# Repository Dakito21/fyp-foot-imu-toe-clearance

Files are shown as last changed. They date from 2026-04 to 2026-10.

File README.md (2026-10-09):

# Foot-Mounted IMU Estimation of Minimum Toe Clearance

Final Year Project, Robotics and Mechatronic Engineering, Monash University (2026).
Supervisor: Dr Alpha Agape Gopalai.

Minimum toe clearance (MTC) is the smallest gap between the toe and the ground during the swing phase of walking, and is closely linked to trip and fall risk. It is normally measured with optical motion capture (MoCap), which only works in a lab. This project estimates MTC from a single foot-mounted IMU instead. It also includes a low-cost wearable IMU (BMI160 + Seeed XIAO nRF52840 Sense) that I designed, built and programmed.

📄 **Paper:** [paper/FYP_Final_Paper.pdf](paper/FYP_Final_Paper.pdf)

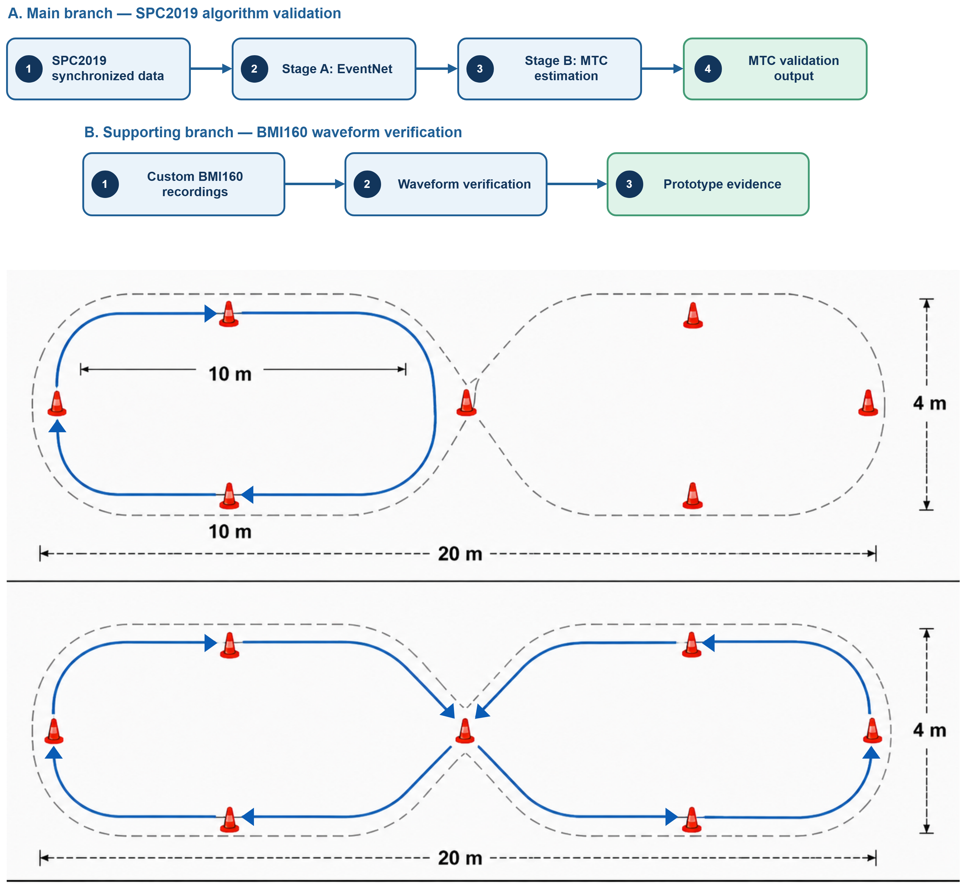
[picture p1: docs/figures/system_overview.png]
System overview: SPC2019 algorithm validation branch and BMI160 waveform verification branch


## Results

The algorithm was validated against synchronised MoCap from the [SensorPositionComparison2019](https://mad-lab-fau.github.io/gaitmap-datasets/auto_examples/sensor_position_comparison_2019.html) dataset, using participant-held-out gait-event detection on 12 participants and all 7 walking trials.

| Matched strides | Bias (IMU − MoCap) | MAE | RMSE | Pearson r |
|---:|---:|---:|---:|---:|
| 7142 | −3.0 mm | 8.64 mm | 11.40 mm | 0.674 |

- **Gait events:** the toe-off and initial-contact detector matched 81.3% of reference events, with a mean absolute timing error of 12.5 ms (toe-off) and 9.9 ms (initial contact).
- **Best walking condition:** normal-speed walking over 20 m gave the best agreement, with an MAE of 7.4 mm and an RMSE of 9.7 mm.
- **Custom hardware:** the BMI160/XIAO prototype captured repeatable gait-cycle gyroscope peaks that change with walking speed, compared against SPC2019 right-instep recordings. This shows the signals are plausible; the prototype's own MTC accuracy has not been validated yet.

## Pipeline

1. **Gait-event detection (Stage A EventNet):** a compact 1D dilated CNN (kernel 7, dilations 1/2/4) that labels stance and swing from 8 IMU channels, followed by hysteresis to recover toe-off (TC) and initial-contact (IC) events.
2. **Cadence-adaptive filtering:** zero-phase Butterworth filters with cut-offs scaled from the step frequency: `acc = clip(8·f_step, 10, 35) Hz`, `gyr = clip(6·f_step, 8, 30) Hz`.
3. **Orientation and gravity removal:** a Madgwick filter, stance-attitude correction, and ZUPT (zero-velocity) / minimum-velocity windows.
4. **Stride-local vertical integration:** double integration of vertical acceleration from TC to IC, with endpoint closure to suppress drift.
5. **Virtual toe:** the IMU-to-toe offset is calibrated against MoCap, and MTC is taken as the minimum of toe height above a ground level estimated from stance.
6. **Validation:** monotone dynamic-programming stride matching against MoCap, reporting bias, MAE, RMSE and Pearson r.

**Stage A: gait-event detection**

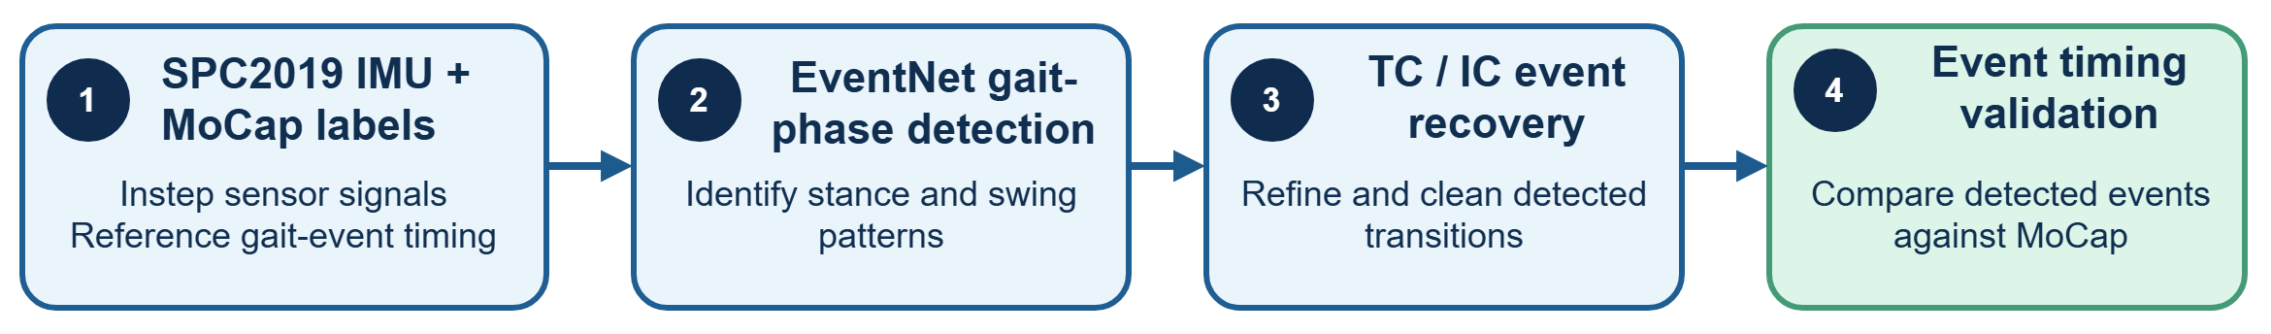
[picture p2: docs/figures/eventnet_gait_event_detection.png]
EventNet gait-event detection pipeline


**Stage B: MTC estimation**

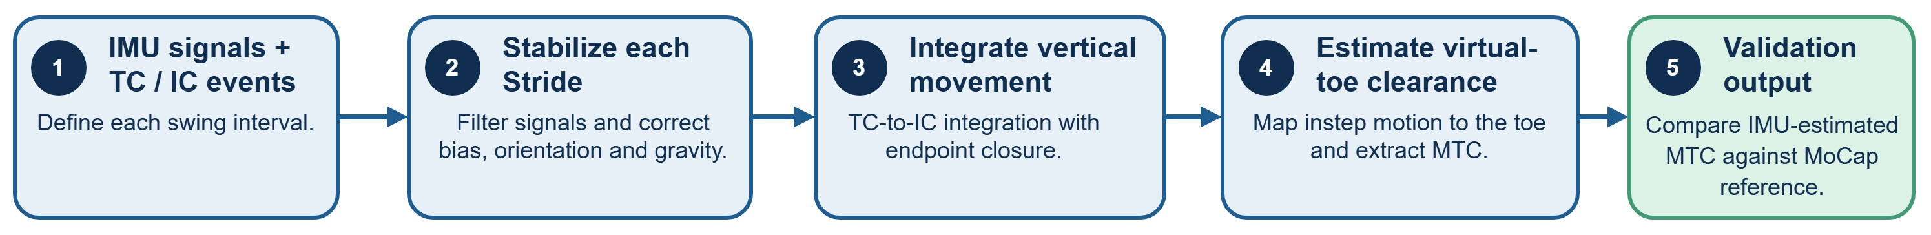
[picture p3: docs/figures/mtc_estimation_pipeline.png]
IMU-based MTC estimation pipeline


**BMI160 prototype: waveform verification**

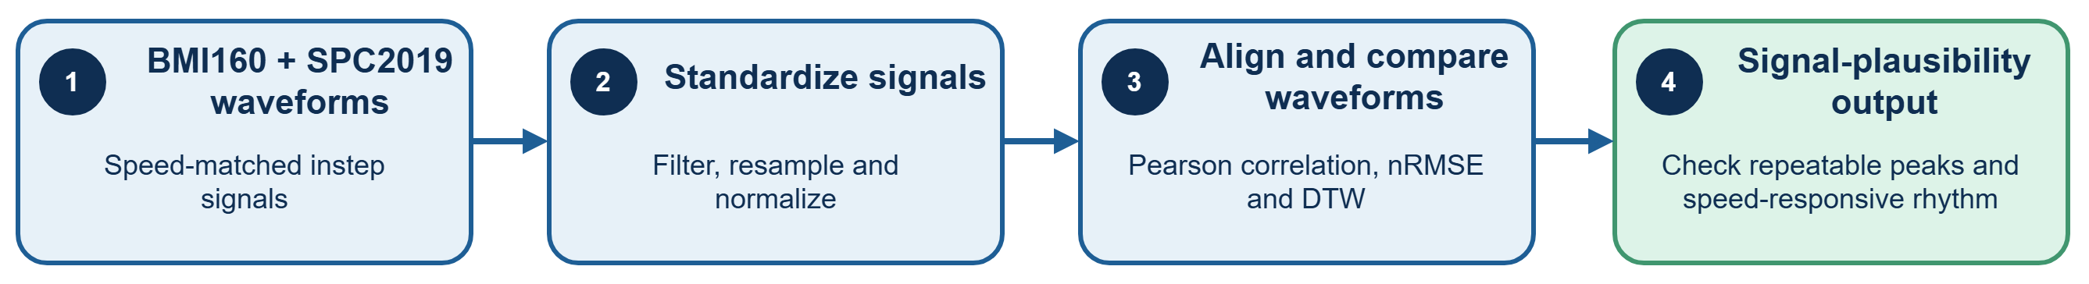
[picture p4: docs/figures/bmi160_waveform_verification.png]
BMI160 waveform verification pipeline


## Hardware

The wearable uses a BMI160 6-axis IMU on I²C with a Seeed Studio XIAO nRF52840 Sense, powered by a 3.7 V LiPo through a slide switch. Data is recorded to RAM at 200 Hz and sent to a host PC over BLE in acknowledged chunks. The 3D-printed enclosure went through seven design iterations ([`hardware/enclosure_cad/`](hardware/enclosure_cad/)).

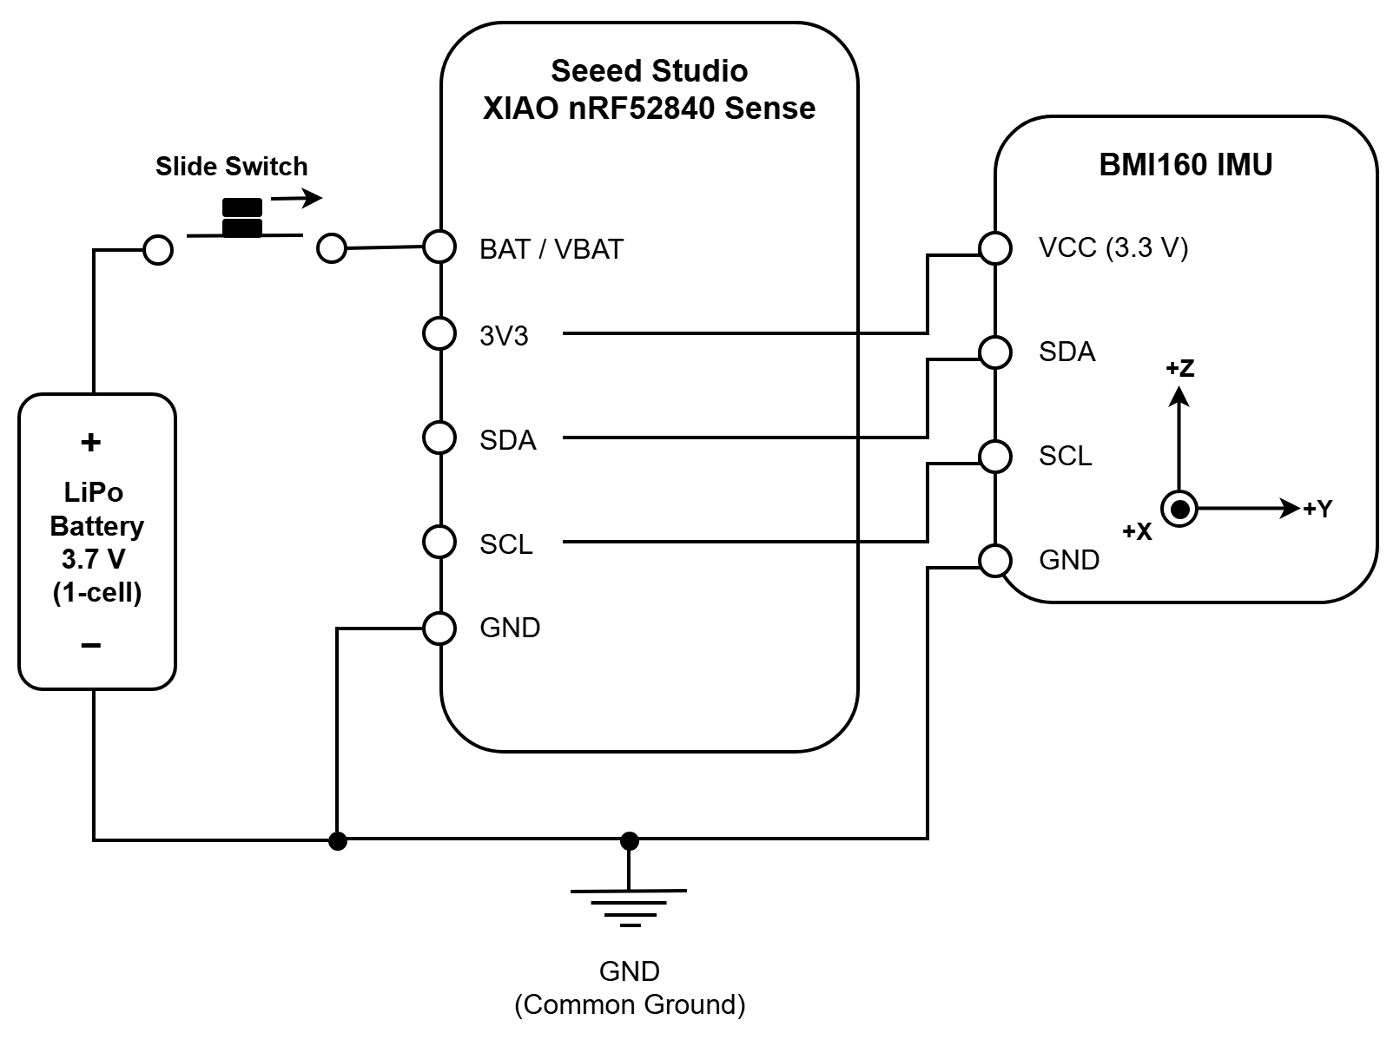
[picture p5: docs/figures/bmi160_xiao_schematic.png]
BMI160 / XIAO nRF52840 schematic


## Repository layout

| Path | Contents |
|---|---|
| [`algorithm/mtc_pipeline.py`](algorithm/mtc_pipeline.py) | Core signal processing: phases 1.1–1.9 (loading, filtering, events, orientation, integration, MTC, validation) |
| [`algorithm/pipeline_core.py`](algorithm/pipeline_core.py) | Wrapper that runs the phases in order and caches intermediate results |
| [`algorithm/calibrate_toe_offset.py`](algorithm/calibrate_toe_offset.py) | Coarse-to-fine IMU-to-toe offset calibration |
| [`algorithm/evaluate.py`](algorithm/evaluate.py) | Runs the pipeline with fixed (frozen) parameters and writes a summary CSV |
| [`algorithm/train_eventnet_stageA.py`](algorithm/train_eventnet_stageA.py) | EventNet training; trained weights in [`param_stageA.pt`](algorithm/param_stageA.pt) |
| [`algorithm/metrics_from_imu_only_summary.py`](algorithm/metrics_from_imu_only_summary.py) | Aggregates per-trial summaries into per-participant metrics |
| [`algorithm/experiments/`](algorithm/experiments/) | Upper-bound baseline that uses MoCap gait events |
| [`algorithm/tools/`](algorithm/tools/) | Early helper scripts: batch runner over participants, comparison CSV export, error statistics |
| [`hardware/enclosure_cad/`](hardware/enclosure_cad/) | SolidWorks enclosure design, V1 to V7 (`.SLDPRT` parts, `.STL` exports, V2 assembly); V7 is the final casing. GitHub previews the `.STL` files in 3D |
| [`hardware/firmware/`](hardware/firmware/) | XIAO nRF52840 Arduino sketches; `GyroAndAccel_Recording_V2` is the final recording firmware |
| [`hardware/host/`](hardware/host/) | Bluetooth Low Energy (BLE) logger using a three-way ACK/NACK handshake, plus stage 0–2 IMU calibration and the recordings it was fitted from (`calibration/data/`) |
| [`waveform_comparison/`](waveform_comparison/) | Comparison of BMI160 and SPC2019 waveforms; `plots/` is v2 (gaitmap frame), `plots_v1/` is the first version |
| [`data/bmi160_recordings/`](data/bmi160_recordings/) | Raw and calibrated walking recordings from the custom device |
| [`results/`](results/) | Per-trial summaries, toe-offset calibrations and stride-level error exports |
| [`docs/`](docs/) | Pipeline, system and circuit diagrams (`figures/` PNG exports, `diagrams_source/` editable draw.io files) |

The SPC2019 dataset is not included. Download it from the link above and pass its folder as `--data_folder`.

## Running

Developed with Python 3.10; `requirements.txt` pins the versions from the original environment.

```bash
pip install -r requirements.txt
cd algorithm

# Train the gait-event detector (hold out one participant for validation)
python train_eventnet_stageA.py --data_folder path/to/sensorpositoncomparison-v1.0.0-beta --val_participant 4d91

# Calibrate the toe offset for one participant and side
python calibrate_toe_offset.py --data_folder path/to/... --participant 4d91 --side left \
    --event_source ml --event_model_pt param_stageA.pt

# Evaluate with the calibrated offsets
python evaluate.py --data_folder path/to/... --toe_offset_csv ../results/toe_offset_calibration_xz.csv \
    --event_source ml --event_model_pt param_stageA.pt
```

## Status of the code

This repository contains the most recent versions of the scripts that I still have: the algorithm as of March 2026 and the hardware and waveform-comparison code as of May 2026. The paper's final reported run included further changes that are not in these files:

- strict-nested training with one EventNet checkpoint per held-out participant
- a transition-aware loss with TC/IC edge outputs
- a least-squares seed for the two-stage toe-offset calibration
- the 12-participant waveform comparison

As a result, rerunning this code will not reproduce the paper's tables exactly.

## Commit history

This project was developed without git. The commit history was rebuilt afterwards from dated file snapshots: each earlier version of a script became a commit, dated with that file's last-modified time. Running `git log --follow algorithm/mtc_pipeline.py` shows the pipeline's development from the first IMU-only version (January 2026) to the latest one. Intermediate commits are snapshots and may not run on their own.

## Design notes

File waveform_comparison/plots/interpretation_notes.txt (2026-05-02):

Raw visual comparison notes\n===========================\n\nDataset target: 4d91 / normal_10 / right / r_instep.\nDataset data are loaded through core.load_trial(), which uses SensorPositionComparison2019Mocap.\nThe gaitmap dataset loader transforms foot-mounted sensors into the gaitmap coordinate system.\n\nUnit handling:\n- Acceleration: dataset m/s²; BMI160 g converted to m/s².\n- Gyroscope: dataset deg/s; BMI160 deg/s.\n- This v2 script no longer treats dataset gyro as rad/s.\n\nAxis handling:\n- BMI160 -> gaitmap axis map used: +x,+y,+z\n- Default map assumes BMI160 +z is top/outward, +y is casing-left, +x is toe/front.\n- Norm plots are still the safest comparison because exact sensor placement and shoe alignment can differ.\n\nRecommended figures for professor review:\n1. 00_window_selection_diagnostics.png\n2. 03_acc_norm_comparison.png\n3. 04_gyr_norm_comparison_degps.png\n4. 05_zscore_norm_shape_comparison.png\n5. 06_axis_overlay_gaitmap_frame.png only if discussing axis mapping.\n

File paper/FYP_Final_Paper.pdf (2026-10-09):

1

# Foot-Mounted IMU Estimation of Minimum Toe Clearance with Low-Cost Wearable Signal Verification

Dayyan Safiuddin bin Jamal Sharifuddin, Author, Dr Alpha Agape Gopalai, Supervisor, Department of Robotics and Mechatronic Engineering

Abstract— Minimum toe clearance (MTC) is an important gait parameter for trip-risk assessment, but conventional motion capture (MoCap) measurement is laboratory-dependent and unsuitable for routine monitoring. This study evaluates a foot-mounted inertial measurement unit (IMU) workflow for estimating MTC and investigates whether a low-cost custom wearable prototype can capture plausible gait-related inertial signals. The algorithmic pipeline was validated using the SensorPositionComparison2019 (SPC2019) dataset, which provides synchronized foot-mounted IMU and MoCap recordings. A strict-nested EventNet gait-event detector was used to identify toe-off and initial-contact events, followed by adaptive stride-local vertical integration, virtual toe kinematics, MoCap-referenced toe-offset calibration, and stride-level IMU-MoCap comparison. The final reported validation used the 12 completed participant cohort; two indexed participants were excluded from final MTC metrics because held-out ML event recovery produced no valid stride matches for two-stage MoCap-referenced toe-offset calibration under the fixed matching criteria. Across 7142 matched strides, the IMU-based estimator achieved an overall MTC bias of -3.000 mm, MAE of 8.638 mm, RMSE of 11.401 mm, and Pearson correlation of r = 0.674. Normal-speed walking produced the most stable agreement, while fast trials and long mixed-speed walking showed greater sensitivity to event timing and stride matching. A separate BMI160/XIAO prototype was also developed and verified at the signal level using gyroscope-norm waveform comparison against SPC2019 right-instep references. The prototype captured repeatable gait-cycle peaks and speed-dependent rhythm changes, supporting hardware signal plausibility but not direct MTC accuracy. Overall, the work supports a staged validation pathway in which the offline IMU algorithm is technically promising, while the low-cost prototype requires synchronized BMI160-MoCap testing before direct MTC validation can be claimed.

Index Terms—Gait analysis, inertial measurement units, minimum toe clearance, motion capture, wearable sensors.

I. INTRODUCTION
inimum toe clearance (MTC) is the minimum vertical distance between the toe and walking surface during the swing phase of gait. It is often discussed under minimum foot clearance (MFC), which is associated with trip risk because the swing foot passes close to the ground during mid-swing [1]. Accurate MTC estimation is therefore relevant for gait safety, fall-risk assessment, and walking-performance analysis. Although optical motion capture (MoCap) provides accurate marker-based clearance measurements, its high cost, laboratory dependence, and limited practicality make it unsuitable for routine or real-world

monitoring [1], [2].
To address these limitations, wearable inertial measurement units (IMUs) offer a portable and lower-cost alternative to MoCap. By measuring acceleration and angular velocity, IMUs can support gait-event detection, foot-trajectory estimation, and lower-limb movement analysis [2], [3]. Previous studies have shown that foot-mounted IMUs can estimate heel, toe, and foot clearance [2], [3], while recent work has improved wearable clearance estimation using single foot-mounted IMUs combined with shoe-geometry models [4].

Despite this potential, IMU-based MTC estimation remains challenging because IMUs do not directly measure displacement. Foot or toe trajectory must be reconstructed by transforming acceleration into a reference frame and integrating it twice, making the estimate sensitive to sensor bias, orientation error, gait-event timing error, and drift [2]. These issues are particularly important because MTC occurs during swing, where errors in toe-off, final contact, or initial contact detection can alter the integration window and affect the estimated clearance. Deep-learning gait-event detection has shown good agreement with optical motion-capture references, supporting its use in IMU-based gait pipelines [5].

These challenges show that wearable clearance estimation requires not only an appropriate IMU processing method, but also careful validation against reliable reference data. Existing studies demonstrate the feasibility of wearable clearance estimation while highlighting the importance of sensor placement, calibration, drift correction, gait-event detection, and reference-based validation [2]–[4]. This project therefore uses the SensorPositionComparison2019 dataset, hereafter referred to as SPC2019 dataset because it provides synchronized foot-mounted IMU and MoCap recordings across multiple walking tests and sensor positions, allowing direct comparison between IMU-estimated and MoCap-derived MTC [6], [7].

Beyond algorithm validation, a further practical issue is whether a low-cost custom wearable IMU device can capture usable gait-related inertial signals. Many studies validate clearance algorithms using research-grade sensors or controlled laboratory setups, while fewer examine the earlystage feasibility of custom low-cost devices for this purpose. Therefore, this project separates algorithm validation from hardware verification. The MTC algorithm is validated using SPC2019 MoCap reference data, while the custom BMI160/XIAO-based prototype is assessed at the raw-signal

M

2

level by comparing its waveform morphology with reference foot-mounted IMU recordings [8], [9]. Pearson correlation, normalized root mean square error (nRMSE), cross-correlation, and dynamic time warping (DTW) are used because they assess waveform similarity under amplitude and timing differences [10].

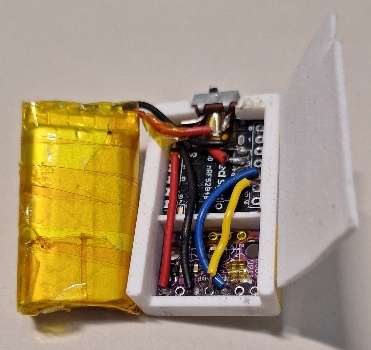
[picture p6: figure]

The objective of this work is therefore to evaluate whether a foot-mounted IMU processing pipeline can estimate MTC with acceptable agreement against MoCap reference data, and whether a low-cost custom IMU prototype can capture recognizable gait-related inertial patterns. The contributions are:
1) Implementation of a foot-mounted IMU-based MTC pipeline using SPC2019.
2) Comparison of estimated MTC against synchronized MoCap data.
3) Development of a low-cost BMI160/XIAO wearable IMU prototype.
4) Preliminary signal-level verification of the prototype against reference IMU waveforms.

II. HARDWARE SYSTEM
A. Circuit Design and Sensor Integration
The custom BMI160 device was designed under low-cost, wearable-size, untethered-operation, and shoe-mounting constraints. An external BMI160 IMU was connected to a Seeed Studio XIAO nRF52840 Sense microcontroller, with the BMI160 measuring triaxial acceleration and angular velocity while the XIAO handled I2C communication, BLE transfer, and battery-supported operation [8], [9]. The circuit used SDA, SCL, 3.3 V, and ground, with a common ground maintained across the IMU, microcontroller, battery, and slide switch to support stable readings. A lithium-polymer battery and slide switch enabled untethered walking and safe isolation during mounting, handling, and storage.
B. CAD Enclosure

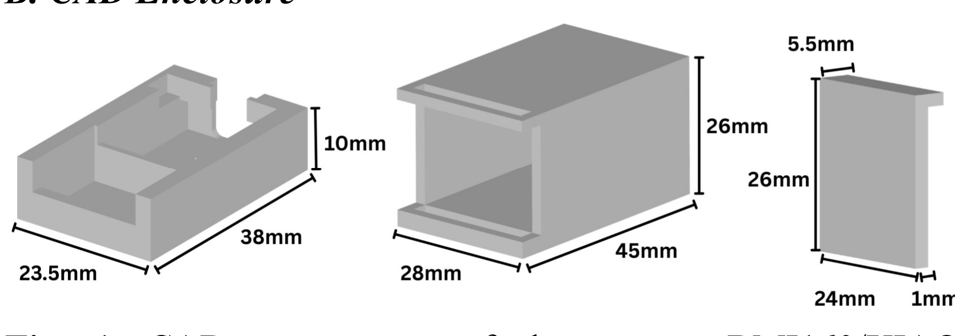
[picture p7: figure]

Fig. 1. CAD components of the custom BMI160/XIAO wearable enclosure, showing the bottom layer (left), outer shell (middle), and shell door (right).

A custom two-layer CAD enclosure with dimensions of 45 × 26 × 28 mm was designed as a compact wearable casing. The top layer housed the lithium-polymer battery, while the bottom layer contained the BMI160 IMU, XIAO nRF52840 Sense microcontroller, slide switch, and wiring.

Mechanical stability was the main design consideration because foot-mounted IMU outputs are affected by sensor placement and fixation during walking [7]. The component slots were dimensioned to closely fit the BMI160 and microcontroller, reducing internal movement while preserving wiring clearance, USB access, battery placement, and ease of assembly.

C. Fabrication and Assembly
After CAD design, the
battery, slide switch, XIAO
nRF52840 | Sense
microcontroller, and BMI160 IMU were soldered together to reduce loose connections during walking trials. The lithium-polymer battery was insulated with electrical tape before being placed in the top layer of the casing.

EVA foam was
added inside the
battery
compartment
and between the
battery and
lower
electronics

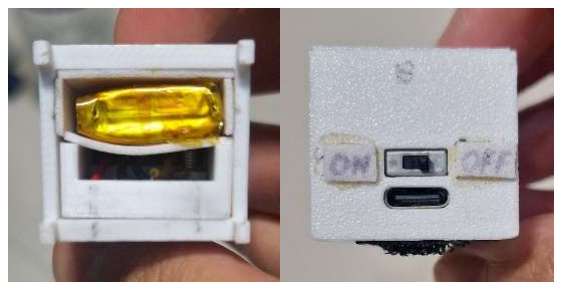
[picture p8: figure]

layer to improve fit, reduce battery movement, and separate the battery from the microcontroller, IMU, and wiring. A 2.5 mm drill bit was also used to drill through the casing so the BMI160 could be fastened tightly, reducing relative movement between the sensor and enclosure during walking [7].

Fig. 2. Fabricated BMI160/XIAO prototype and internal assembly details.

D. Shoe Mounting

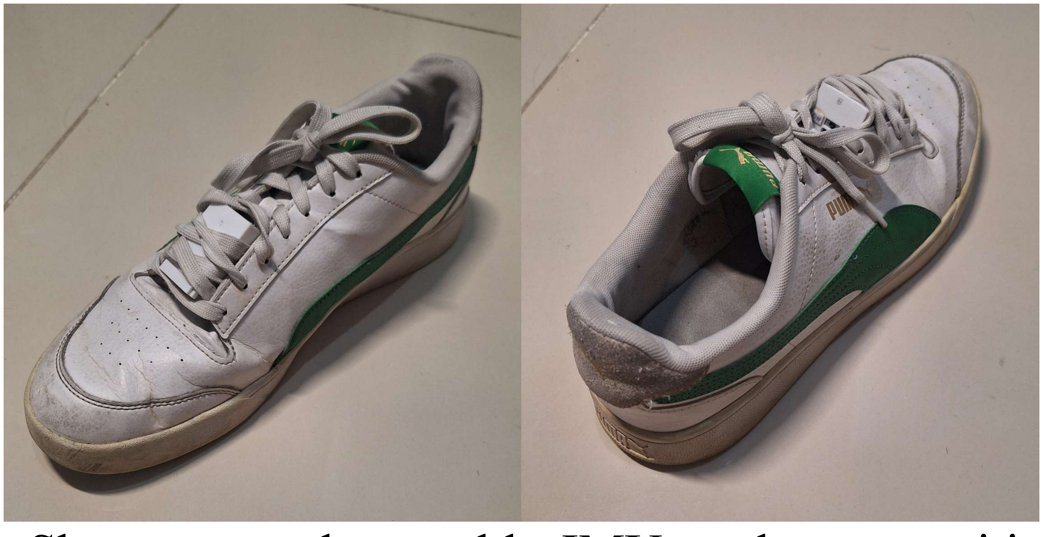
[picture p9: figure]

Fig. 3. Shoe-mounted wearable IMU enclosure positioned at the instep/tongue region and secured using interlaced shoelaces.

The enclosure was mounted near the shoe instep/tongue region using Velcro strap tape and shoelaces. Velcro was attached to the shoe tongue and casing base to reduce movement, while the shoelaces provided additional fastening. This position was selected because it was the closest practical match to the SPC2019 instep sensor location used for comparison [6], [7].

This mounting position balanced sensor fixation, walking comfort, accessibility, and reduced swing-phase obstruction. The same attachment method was used across slow, normal,

3

and fast trials to reduce variation from placement, tightness, or casing slip [7].

E. BLE Data Transfer
Bluetooth Low Energy (BLE) was used to transfer IMU data to a host computer without a physical tether, consistent with the wireless capability of the XIAO nRF52840 platform [9]. Each sample was transmitted as a structured row containing timestamp, triaxial acceleration, and triaxial angular velocity, then saved as trial-specific CSV files.

To improve transfer reliability, a simple three-way handshake was used. The host initiated recording, the device transmitted CSV data in chunks after recording stopped, and the host returned ACK/NACK responses to confirm receipt or request retransmission before the next chunk.

III. DATASET
This project used two data sources: the online SPC2019 dataset and custom recordings from the low-cost BMI160 device. SPC2019 was used because it was recorded using commercial Nilspod IMU sensors with synchronized MoCap data, making it suitable for comparison with the custom BMI160 prototype [6], [7]. The full dataset contains 14 participants [6].
A. SPC2019 Dataset
SPC2019 contains walking trials recorded with IMU sensors attached to both feet, together with synchronized MoCap data [6], [7]. Each participant has seven walking trials: slow_10, normal_10, fast_10, slow_20, normal_20, fast_20, and long [6]. The slow, normal, and fast labels refer to the participant's preferred walking speed for each condition, while 10 and 20 refer to the walking distance before turning. The long trial combines slow, normal, and fast walking within one continuous recording.
B. Selected IMU and MoCap Signals
For MTC validation, SPC2019 triaxial acceleration and angular velocity from the evaluated instep-mounted foot sensors were used [6], [7]. The corresponding MoCap foot/toe marker trajectories provided the stride-level reference MTC. For BMI160 waveform verification, only SPC2019 right-instep IMU signals were used because the custom prototype was mounted on the right shoe, keeping the synchronized MTC-validation branch separate from the unsynchronized BMI160 plausibility branch.
C. Custom BMI160 Walking Recordings
The custom BMI160 recordings were collected using the wearable device described in Section II. Each CSV file contained timestamp, triaxial acceleration, and triaxial angular velocity, matching the main IMU signal types available in SPC2019 [6], [8].

Each recording lasted 30 s in a long, flat corridor. The participant started walking approximately 5 s after recording began, creating a short stationary segment before the walking segment. To match SPC2019, separate slow, normal, and fast trials were recorded using the participant's preferred walking speed for each condition [6]. Because these recordings were not synchronized with MoCap, they were used only for waveform plausibility rather than direct MTC validation.

D. Trial Conditions and Walking Speeds
For shape verification, the SPC2019 20 m trials were used as the main comparison set because they were closest to the custom corridor recordings [6]. The 10 m trials were kept as additional speed-matched comparisons.

The long trial was excluded from shape verification because it combines all three walking speeds in one continuous recording, making it less suitable for separate slow, normal, and fast waveform comparison [6], [10].

IV. METHODOLOGY
The MTC validation pipeline used the SPC2019 signals defined in Section III and combined a participant-held-out deep-learning gait-event detector, adaptive stride-local inertial processing, virtual toe kinematics, MoCap-referenced toe-offset calibration, and matched IMU-MoCap validation. The gait-event detector is referred to as Stage A EventNet in this paper because it represents the first-stage TC/IC detection model used before MTC estimation. Standard IMU clearance steps such as filtering, orientation estimation, integration, and agreement metrics are stated briefly, while the project-specific design choices are described in more detail [2]–[5], [12], [13]. The BMI160 route remained a separate waveform-plausibility check because those recordings were not synchronized with MoCap [10]. The main methodological trade-off was that MoCap-referenced calibration improved offline MTC agreement, but it also prevented the current method from being claimed as a deployment-ready field system.
A. Pipeline Overview and Notation
TC denotes toe-off, IC denotes initial contact, and signed MTC error was defined as IMU estimate minus MoCap reference. MTC values were reported in millimeters. The MoCap toe marker was used as the reference trajectory for stride-level MTC comparison.
B. Dataset Loading and Trial Definition
Each SPC2019 trial was loaded by participant, walking test, and side, with 3.0 s padding added to stabilize filtering and event processing near the analysed region. MoCap gait events were converted to the IMU sample axis so detected IMU events and reference events used the same time base [6], [7].

The evaluated SPC2019 MTC set included slow_10, normal_10, fast_10, slow_20, normal_20, fast_20, and long [6]. The long trial was treated as a continuous mixed-speed walk, so adaptive processing used stride-level gait state rather than speed labels. Results were reported for the 12 completed participants; 54a9 and 8873 were excluded because the strict ML EventNet path produced no valid matched strides before Method 1 toe-offset calibration.

4

C. Strict-Nested EventNet Gait-Event Detection
The strict-nested EventNet gait-event detection workflow is summarised in Fig. 4.

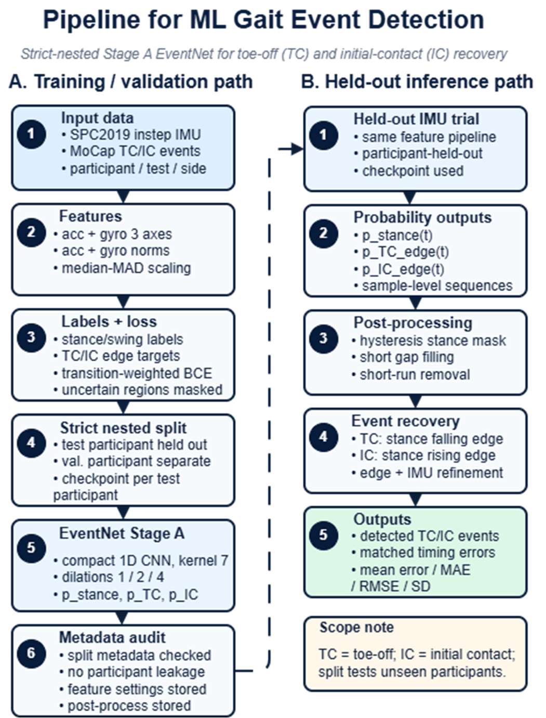
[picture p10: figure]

Fig. 4. Strict-nested EventNet gait-event detection pipeline for TC and IC gait-event detection from SPC2019 instep IMU data.

1) Feature Construction
EventNet was trained from instep IMU features: triaxial acceleration, triaxial angular velocity, acceleration norm, and gyroscope norm.
x = [a

, ω

, ∥ a ∥

, ∥ ω ∥

] | (1)
where a
is the triaxial acceleration vector, ω | is the triaxial
angular-velocity vector, and x

is the eight-channel EventNet input at sample t. These channels are standard inputs for IMU-based deep-learning gait-event detection [5]. The project specific preparation was the use of per-trial median and median absolute deviation scaling, which made feature normalization more robust to participant- and trial-level amplitude differences before inference.

2) Labels and Transition-Aware Loss
MoCap-derived TC and IC events were converted to the IMU time base and used to generate dense stance/swing labels. Swing was defined over TC-to-IC, reliable stance samples were labelled as stance, and uncertain stride regions were masked from the loss. The nonstandard design choice was the transition-aware EventNet loss: samples near TC and IC were weighted more heavily, and auxiliary TC/IC edge targets were added so the network learned both gait phase and boundary timing [5].
ℒ = ℒ + 0.5ℒ + 0.5ℒ | (2)
where ℒis the weighted stance/swing binary crossentropy loss, while ℒand ℒare auxiliary edge-detection losses around TC and IC. Samples within ±50ms of TC or IC received higher stance-loss weighting, and TC/IC edge targets used ±20ms positive windows.
3) Network Architecture and Strict Nested Splits
The Stage A EventNet model was a compact fully convolutional 1D network with three temporal convolution blocks using kernel size 7 and dilations 1, 2, and 4, followed by a 1x1 output head. This kept the model small while giving enough temporal context for gait-event localization, consistent with convolutional IMU gait-event approaches [5]. In transition-aware mode, the network output stance probability plus TC- and IC-edge probabilities.

Participant leakage was controlled using strict nested splits. For each evaluated participant, a separate checkpoint was trained with that participant excluded from both training and validation; a different participant was used for validation, and all remaining participants formed the training set. The evaluated test/validation pairs were 4d91/5047, 5047/5237, 6e2e/80b8, 9b4b/c9bb, and e54d/4d91. This split design was retained because MTC validation should test generalization to unseen participants, not memorization of participant-specific gait patterns.

4) EventNet Inference and Event Recovery
At inference, the filtered IMU signal was transformed into the same feature set and passed through the participant-held-out checkpoint. The stance-probability sequence was converted into a binary stance mask using hysteresis, short gaps were filled, and unrealistic stance or swing runs were removed. TC and IC were then recovered from stance transitions, with the auxiliary edge heads and local IMU cues used only for boundary refinement [5].
D. Adaptive Stride-Local MTC Estimation
The IMU-based MTC estimation workflow, including stride-local integration, two-stage MoCap-referenced toe-offset calibration, and MoCap validation, is summarised in Fig. 5.

5

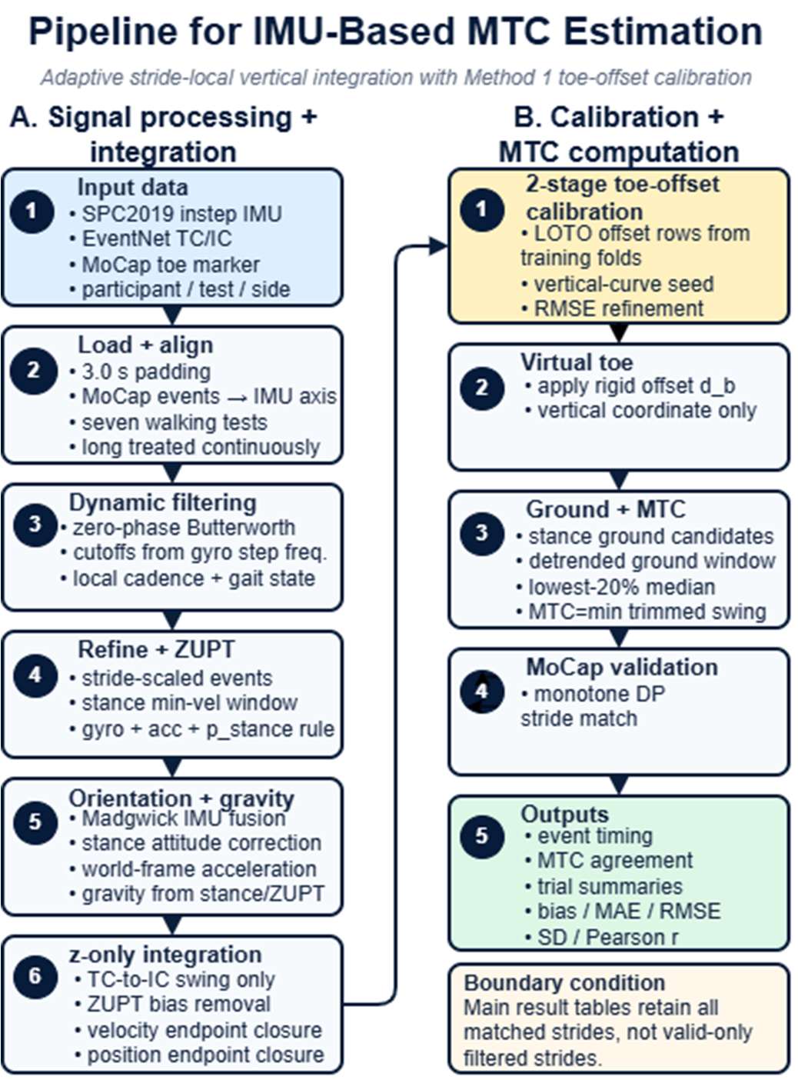
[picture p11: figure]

Fig. 5. IMU-based MTC estimation pipeline using adaptive stride-local vertical integration, two-stage MoCap-referenced toe-offset calibration, and MoCap-referenced validation.

1) Dynamic Filtering and Local Gait State
Before event detection and inertial integration, accelerometer and gyroscope channels were filtered with a fourth-order zerophase Butterworth filter to reduce noise without introducing timing delay [11]. Cadence-adaptive cut-off selection was used: cut-offs were scaled from the gyro-norm step frequency and clipped within bounded ranges, so slow, normal, fast, and long trials were handled using local gait dynamics rather than a single fixed filter setting [6], [7].
f = clip8f, 10,35,
f = clip6f, 8,30 | | (3)
where f is the dominant step frequency estimated from the
gyroscope-norm spectrum, while f | and f | are the
acceleration and gyroscope low-pass cut-off frequencies in Hz.
2) Adaptive Event Refinement and ZUPT Selection
Coarse EventNet TC and IC timings were refined using windows scaled by local stride duration. Slow strides were given wider refinement windows, while fast strides used narrower windows to reduce overcorrection. The local ZUPT or minimum-velocity window was selected inside stance using low gyroscope norm, low acceleration variation, and high EventNet stance probability, following foot-mounted zero-velocity principles but adding stance-probability evidence from the ML detector [12].
3) Orientation, Stance Attitude Correction, and Gravity Removal
Orientation was estimated using the Madgwick IMU filter [13]. Gyroscope values were converted to radians per second, with stronger correction during stance/ZUPT and weaker correction during swing. A conservative stance-attitude correction aligned the estimated gravity direction with measured quiet-stance acceleration, after which acceleration was rotated into the world frame and gravity was removed using stance/ZUPT samples where available.
a, = R(q)a,
,
a, = a, − g | (4)
where a,

is body-frame acceleration, R(q ) is the rotation
matrix from the estimated orientation, a, | is world-frame
acceleration, and g is the stance/ZUPT gravity estimate.
4) Stride-Local Vertical Integration
The estimator used z-only stride-local integration. For each TC-to-IC swing, vertical acceleration bias was estimated from the local stance/ZUPT window, then vertical velocity and displacement were integrated only across that swing.

v, = v, + a,,

− b,Δt,
p, = p, + v,Δt | (5)
where b, is the stride-specific vertical acceleration bias estimated from the local stance/ZUPT window for stride k. Endpoint velocity and position were closed at IC to suppress stride-level drift. This design was used because MTC is a vertical clearance quantity and avoiding full-trial 3D trajectory reconstruction reduced exposure to heading drift, horizontal bias, and long-trial accumulation error [2], [12].
5) Virtual Toe Kinematics and MTC Extraction
Toe height was estimated using a calibrated rigid IMU-to-toe offset. The body-frame offset was rotated into the world frame and added to the IMU vertical displacement, which is consistent with foot-mounted IMU clearance methods that estimate heel, toe, or shoe points from sensor-to-foot geometry [3], [4].

p, = p, + R(q )d, z, = e

p, | (6)
where d is the calibrated IMU-to-toe offset in the sensor body frame, p,

is the estimated toe position, and z,

is
the vertical toe position. MTC = min
∈S
z,−z, | (7)
where Sis the trimmed swing interval for stride k, and z,is the stride-specific stance-based ground level. Ground height was estimated by robust stance candidates, and the selected window was detrended before using the lowestsample median to reduce stance-rocker bias before extracting MTC [2], [3].
E. Two-stage MoCap-referenced Toe-offset Calibration Toe-offset calibration used a two-stage MoCap-referenced calibration procedure. First, a vertical-curve least-squares estimate was used to seed the IMU-to-toe offset. Second, candidate offsets were refined by minimising training-fold IMU-MoCap MTC RMSE, with absolute bias used only as a tiebreaker. Calibration was run separately for each participant,

6

side, and held-out test, producing leave-one-test-out offset rows that were evaluated using fixed offsets. The search used x = 0 to 8 cm, y = 0 to 10 cm for the left side or -5 to 5 cm for the right side, z = -3 to 3 cm, with no z regularization or forced z = 0 constraint. This was needed because MTC was estimated at the toe, not at the IMU origin [3], [4].

The calibration first used a vertical-curve least-squares seed from the IMU-derived swing trajectory. A low-clearance emphasis made the seed more sensitive to the part of swing that controls MTC. Candidate offsets were then refined by scoring training-fold MTC RMSE against the MoCap reference, with absolute bias used only as a tiebreaker [3], [6], [7].

d

∗ = arg min

∑ e

| (d)
| (8)
where d

∗
is the selected IMU-to-toe offset, e

is the matchedstride IMU-MoCap MTC error for training-fold stride i, and Nis the number of matched training-fold strides. This two-stage design reduced blind grid-search dependence while still choosing the offset that best matched held-out-trial validation.

F. IMU-MoCap Validation
1) Stride Matching and Event Timing
Detected IMU strides were matched to converted MoCap reference strides using monotone dynamic programming based on mid-swing timing. This preserved chronological stride order while allowing missed detections or unmatched references to be skipped [14]. TC and IC timing errors were reported in milliseconds for matched events, and full detected/reference event counts were recovered using the same strict-nested participant-held-out EventNet checkpoints [5].
2) MoCap MTC Reference and Agreement Metrics
MoCap reference MTC was computed from the matched toe-marker trajectory over the swing interval and expressed in millimeters [1], [3], [6], [7]. IMU and MoCap MTC values were joined by matched ground-truth stride ID. Agreement was summarized using standard signed-error, absolute-error, RMSE, SD, and correlation outputs, while the generated artifacts reported event timing, overall MTC agreement, pooled trial summaries, and participant-level diagnostics [2], [3].
G. BMI160 Waveform Verification
The BMI160 waveform-verification workflow is summarised in Fig. 6. This route was kept separate from the MTC validation pipeline because the BMI160 recordings were not synchronized with MoCap.

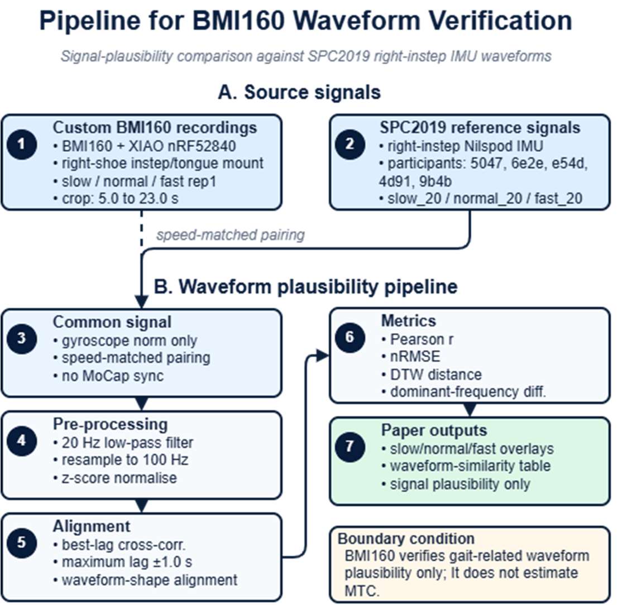
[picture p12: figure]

Fig. 6. BMI160 waveform-verification pipeline for signalplausibility comparison against SPC2019 right-instep IMU waveforms.

1) Signal Preparation
The BMI160 analysis was a waveform plausibility comparison only. It did not perform direct MoCap validation and did not estimate MTC from the BMI160 recordings. The calibrated BMI160 slow, normal, and fast recordings were used. The initial stationary segment was removed by cropping each BMI160 recording from 5.0 s to 23.0 s, and waveform agreement was interpreted only as signal-level similarity rather than biomechanical clearance accuracy [10].
2) Reference Signals and Processing
The BMI160 comparison used SPC2019 right-instep reference signals from the same 12 completed participants used in the final validation cohort [6], [7]. BMI160 slow, normal, and fast rep1 recordings were compared with SPC2019 slow_20, normal_20, and fast_20 respectively using gyroscope norm. The long trial, left-foot signals, and direct BMI160 MTC estimation were excluded from this subsection.
3) Waveform Similarity Metrics
The primary waveform signal was gyroscope norm only. BMI160 and SPC2019 signals were low-pass filtered at 20 Hz where valid, resampled to 100 Hz, z-score normalized, and aligned using best-lag cross-correlation with a maximum lag of +/-1.0 s [11]. Similarity was summarized using Pearson correlation, nRMSE, DTW distance, and dominant-frequency difference; DTW was included because it is a standard dynamic-programming alignment measure for sequences with local timing variation [10], [14].

`

7

V. RESULTS
A. ML Gait Event Detection Validation
1) Event Timing Accuracy
TABLE I
Event Timing Accuracy Summary
Event | Reference events, n | Detected events, n | Matched events, n | Detection rate (%) | Mean error (ms) | MAE (ms)
TC | 8788 | 8650 | 7142 | 81.27 | -9.45 | 12.46
IC | 8788 | 8650 | 7142 | 81.27 | -8.61 | 9.88

Table I summarizes the pooled TC and IC event-detection outputs for the 12 completed participants. Both events had 8788 reference events, 8650 detected events, and 7142 matched events, giving a matched-event detection rate of 81.27%. Mean timing error was -9.448 ms for TC and -8.605 ms for IC, with TC showing larger absolute and spread errors than IC.

2) Event Timing Accuracy by Walking Test
TABLE II
TC Event Timing Accuracy by Walking Test
Metric | slow_10 | normal_10 | fast_10 | slow_20 | normal_20 | fast_20 | long
Reference events, n | 672 | 593 | 505 | 694 | 598 | 517 | 5209
Detected events, n | 765 | 646 | 546 | 693 | 614 | 527 | 4859
Matched events, n | 599 | 544 | 447 | 607 | 548 | 460 | 3937
Detection rate (%) | 89.137 | 91.737 | 88.515 | 87.464 | 91.639 | 88.975 | 75.6
Mean error (ms) | -10.491 | -10.017 | -9.864 | -7.827 | -7.663 | -8.725 | -9.75
MAE (ms) | 12.089 | 11.148 | 10.803 | 9.597 | 8.768 | 9.787 | 14.1
RMSE (ms) | 17.435 | 16.842 | 14.808 | 12.958 | 11.466 | 12.874 | 25.7
SD (ms) | 13.937 | 13.552 | 11.057 | 10.336 | 8.538 | 9.477 | 23.8

TABLE III
IC Event Timing Accuracy by Walking Test
Metric | slow_10 | normal_10 | fast_10 | slow_20 | normal_20 | fast_20 | long
Reference events, n | 672 | 593 | 505 | 694 | 598 | 517 | 5209
Detected events, n | 765 | 646 | 546 | 693 | 614 | 527 | 4859
Matched events, n | 599 | 544 | 447 | 607 | 548 | 460 | 3937
Detection rate (%) | 89.137 | 91.737 | 88.515 | 87.464 | 91.639 | 88.975 | 75.6
Mean error (ms) | -11.975 | -9.658 | -8.739 | -10.248 | -8.982 | -8.874 | -7.6
MAE (ms) | 13.067 | 10.699 | 9.875 | 11.358 | 9.623 | 9.596 | 9.12
RMSE (ms) | 17.417 | 12.676 | 12.093 | 13.932 | 11.39 | 11.287 | 13.5
SD (ms) | 12.657 | 8.217 | 8.369 | 9.446 | 7.011 | 6.983 | 11.2

Tables II and III report event timing by walking test. The shorter speed-specific trials had matched-event detection rates of approximately 87-92%, whereas the long mixed-speed trial had a lower matched rate of 75.581%. This indicates that unmatched events were mainly driven by long-trial stride matching rather than a uniform event-count failure across all walking tests.
3) Event Timing Error Distribution

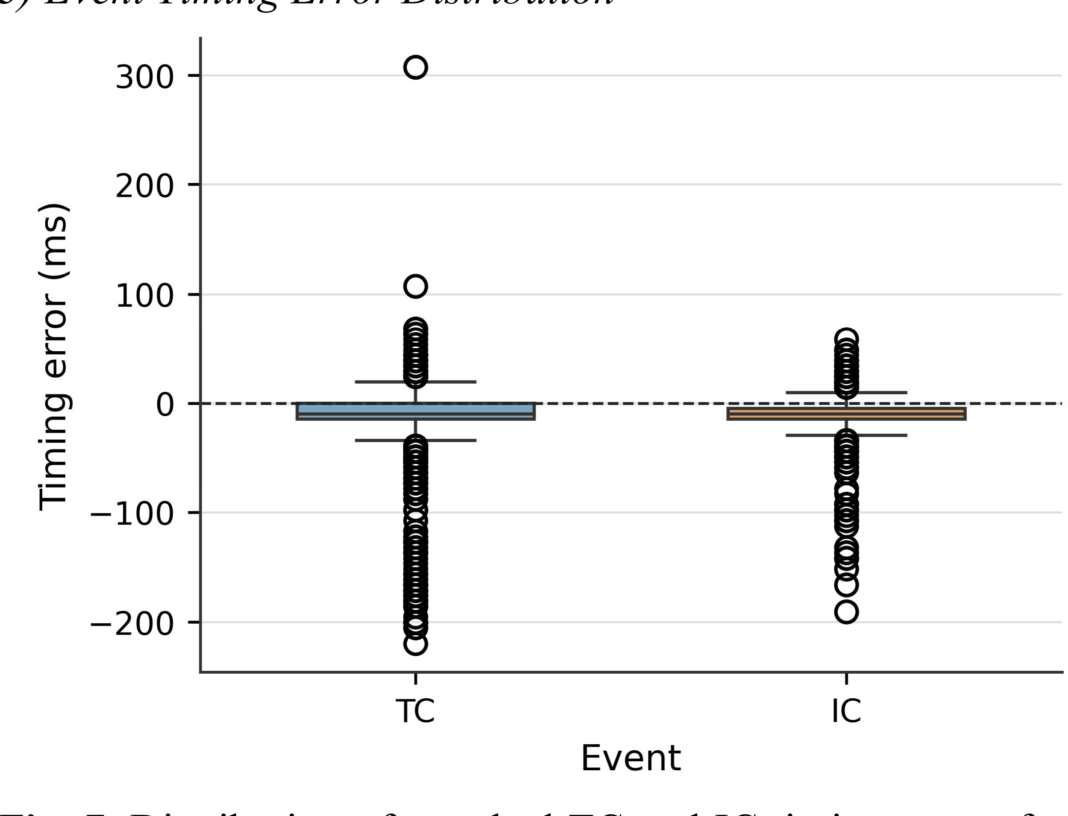
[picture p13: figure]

Fig. 7. Distribution of matched TC and IC timing errors from the strict-nested EventNet gait-event detector.

Fig. 7 presents the matched TC and IC timing-error distributions. Both distributions were centered below zero. TC had a wider spread and more negative outliers than IC, while IC errors were more compact.

B. IMU-Based MTC Estimation Validation
1) IMU-MoCap MTC Agreement

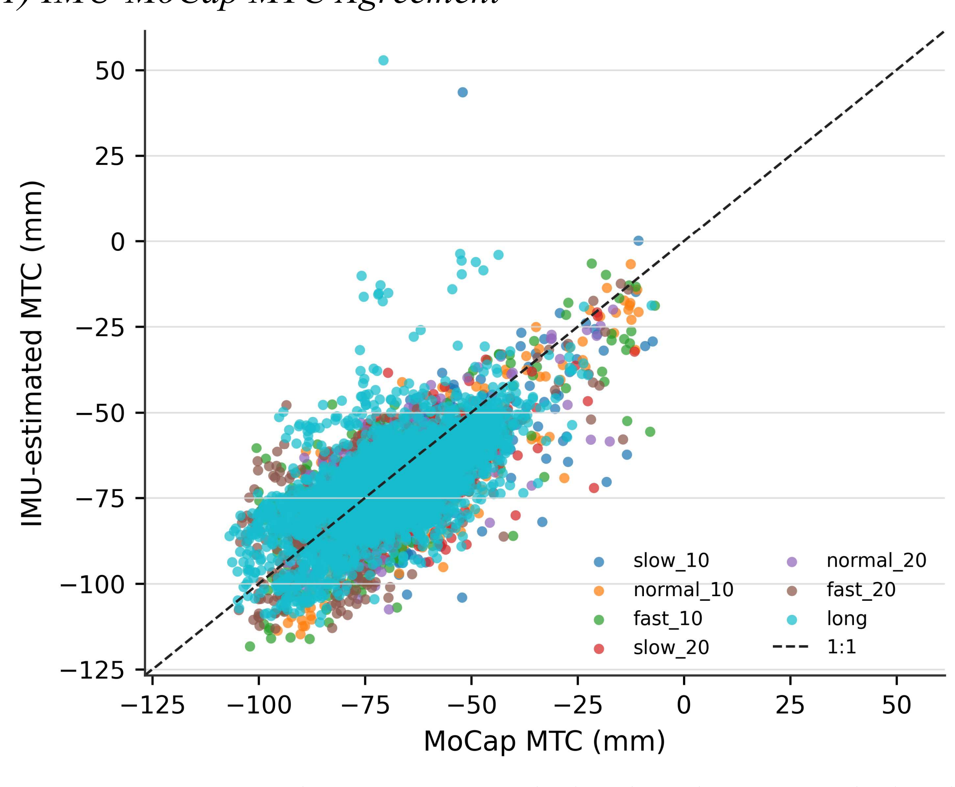
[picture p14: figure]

Fig. 8. Agreement between IMU-derived and MoCap-derived MTC values across matched strides.

8

TABLE IV
Overall IMU-MoCap MTC Agreement Summary
Participants used | Matched strides, n | Mean MoCap MTC (mm) | Mean IMU MTC (mm) | Bias: IMU -MoCap (mm) | MAE (mm) | RMSE (mm) | SD error (mm) | Pearson r
all except for 54a9 and 8873 | 7142 | -67.7 | -70.7 | -3 | 8.64 | 11.4 | 11 | 0.67

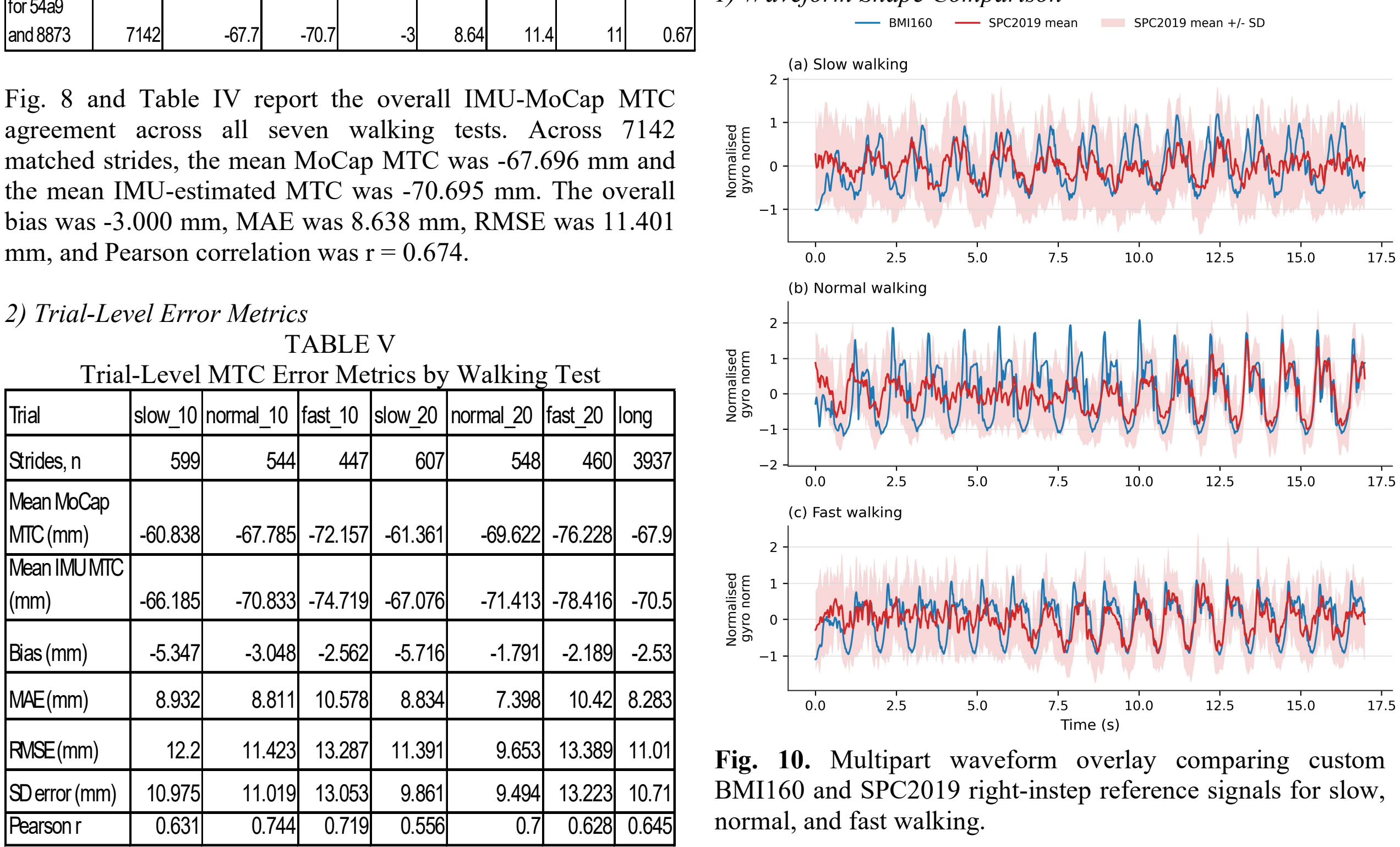
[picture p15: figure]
2) Trial-Level Error Metrics TABLE V; Trial; slow_10; normal_10; fast_10; slow_20; normal_20; fast_20; long; Strides, n; Mean MoCap MTC (mm); Mean IMU MTC (mm); Bias (mm); MAE (mm); RMSE (mm); SD error (mm); Pearson r; normal, and fast walking.

Fig. 8 and Table IV report the overall IMU-MoCap MTC agreement across all seven walking tests. Across 7142 matched strides, the mean MoCap MTC was -67.696 mm and the mean IMU-estimated MTC was -70.695 mm. The overall bias was -3.000 mm, MAE was 8.638 mm, RMSE was 11.401 mm, and Pearson correlation was r = 0.674.

Trial-Level MTC Error Metrics by Walking Test

Table V reports pooled trial-level MTC errors across the 12 completed participants and both sides. The lowest MAE and RMSE occurred in normal_20, at 7.398 mm and 9.653 mm respectively. The highest MAE occurred in fast_10 at 10.578 mm, while the highest RMSE occurred in fast_20 at 13.389 mm. The long mixed-speed trial achieved an RMSE of 11.007 mm.

3) Stride-Level Error Distribution

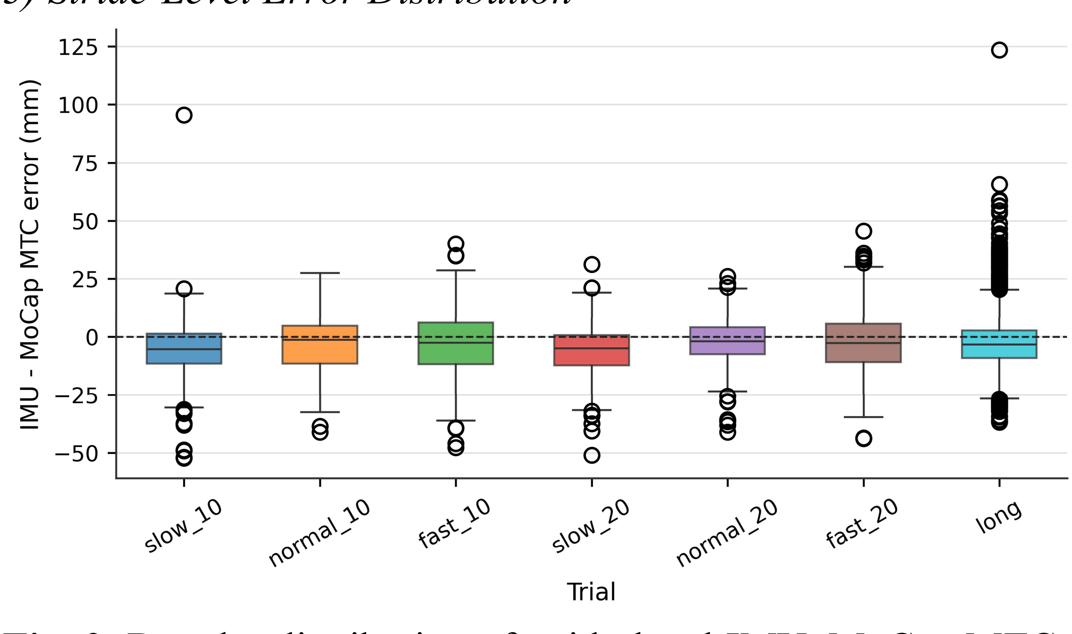
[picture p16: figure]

Fig. 9. Boxplot distribution of stride-level IMU–MoCap MTC error across slow, normal, fast, and mixed-speed walking trials.

Fig. 9 presents stride-level MTC error by walking trial. Errors were mostly centered near zero, with wider spread in the fast trials and visible outliers in the long mixed-speed trial.

C. Custom BMI160 Waveform Verification
1) Waveform Shape Comparison

Fig. 10. Multipart waveform overlay comparing custom BMI160 and SPC2019 right-instep reference signals for slow,

Fig. 10 shows repeated gait-cycle peaks in the BMI160 gyroscope-norm waveform for slow, normal, and fast walking. Peak frequency increased from slow to fast walking. The BMI160 waveform did not match every SPC2019 mean peak, but it retained a recognizable periodic walking pattern.

2) Waveform Similarity Metrics
TABLE VI
Waveform Similarity Metrics
BMI160 trial Walking speed | Slow | Normal | Fast
SPC2019 reference trial | slow_20 | normal_20 | fast_20
Pearson r, mean +/- SD | 0.298 +/- 0.243 | 0.401 +/- 0.176 | 0.325 +/- 0.154
nRMSE, mean +/- SD | 0.309 +/- 0.066 | 0.294 +/- 0.037 | 0.284 +/- 0.045
DTW distance, mean +/- SD | 0.107 +/- 0.017 | 0.093 +/- 0.013 | 0.118 +/- 0.068
Dominant frequency difference (Hz), mean +/- SD | 0.052 +/- 0.064 | 0.021 +/- 0.049 | 0.062 +/- 0.065

Table VI summarizes waveform similarity between the custom BMI160 recordings and the 12-participant SPC2019 right-instep reference windows. Normal walking showed the strongest similarity, with Pearson r = 0.401 +/- 0.176 and nRMSE = 0.294 +/- 0.037. Slow walking was the weakest

9

condition, with Pearson r = 0.298 +/- 0.243 and nRMSE = 0.309 +/- 0.066. These values support waveform plausibility only and do not validate BMI160-derived MTC.

VI. DISCUSSION
A. MoCap-Referenced MTC Performance
The 12-completed-participant results in Table IV and Fig. 8 show that the strict-nested IMU pipeline estimated MoCap-referenced MTC with millimeter-scale disagreement. The negative bias indicates slight underestimation, while the moderate Pearson correlation suggests that the estimator followed the reference trend but retained participant- and trialdependent error.

This supports cohort-level feasibility under controlled SPC2019 conditions, but not universal accuracy. Practical use would still require testing across different hardware, footwear, mounting conditions, walking surfaces, and participants [2]-[4], [6], [7].

B. Event-Matching and Trial-Level Behavior
Table I shows that detected event counts were close to reference counts, but fewer events were matched because timing analysis only included TC/IC events paired one-to-one with MoCap strides under the strict monotone gate. Extra, missing, or shifted detections were audited but excluded from timing-error statistics.

Tables II and III show that mismatch was conditiondependent, with shorter speed-specific trials retaining higher matched-event rates than the long mixed-speed trial. Table V further shows that normal_20 gave the most stable MTC agreement, while fast trials produced larger errors, likely due to greater sensitivity to event-boundary placement, ZUPT selection, endpoint correction, and toe-height extraction [2]-[5], [12].

C. Excluded Participants and EventNet Failure Mode Participants 54a9 and 8873 were excluded because the strict ML EventNet path produced no valid stride matches before Method 1 toe-offset calibration. This was not a post-evaluation RMSE failure; calibration offsets could not be fitted. Diagnostics showed that IMU-only detection recovered many affected strides, while the selected ML checkpoints produced sparse or phase-shifted event sequences that failed the fixed MoCap matching gate.

This suggests that validation BCE loss alone may select checkpoints with acceptable stance-mask loss but poor TC/IC recovery. Future strict-nested training should therefore use validation TC/IC timing metrics and matched-event F1 for checkpoint selection.

D. Bias and Error Mechanisms
The negative MTC bias is likely cumulative rather than caused by one isolated block. Slightly early TC/IC detection can shift the TC-to-IC swing segment used to locate minimum toe height. Residual orientation error and gravity-removal uncertainty may also accumulate during vertical double integration, despite Madgwick filtering, stance correction, ZUPT/minimum-velocity information, and endpoint closure [2]-[4], [12], [13].

The calibrated virtual toe offset adds further uncertainty. Although two-stage MoCap-referenced calibration reduced participant- and side-specific geometry mismatch, the instep-IMU-to-toe relationship was still modelled as a rigid offset. Shoe deformation, strap tension, casing movement, soft-tissue artefact, and marker-to-sensor coordinate differences may therefore shift the estimated toe-height curve [3], [4], [7].

E. BMI160 Waveform Plausibility
The BMI160 branch should be interpreted only as waveform plausibility evidence. The repeated gyroscope-norm peaks in Fig. 10 show that the BMI160/XIAO prototype captured periodic walking-related inertial signals, while the frequency increase from slow to fast walking supports basic speed responsiveness [8], [9].

However, Table VI does not validate BMI160-derived MTC. Pearson correlation, nRMSE, lag-aligned comparison, and DTW assess waveform shape, not toe-clearance accuracy [10], [14]. The device should therefore be described as signal-plausible, not MTC-validated, until synchronized BMI160-MoCap testing is completed.

F. Limitations and Future Work
The main limitation is that each validation branch was constrained by a different evidence level. The SPC2019 branch allowed synchronized IMU–MoCap MTC validation, but only for participants and trials where strict-nested EventNet produced valid matched strides. The BMI160 branch tested the intended low-cost wearable hardware but lacked synchronized MoCap reference data and therefore could support only signal plausibility, not MTC accuracy.

The second limitation is calibration dependency. The two-stage MoCap-referenced toe-offset calibration is suitable for offline dataset validation but not field deployment. A practical system should replace this with direct calibration, anthropometric estimation, shoe-geometry modelling, or another calibration-free approach.

The third limitation is the BMI160 validation level. The custom device was tested with one participant and without synchronized optical reference, so the current evidence supports raw-signal plausibility only. The required next experiment is a synchronized BMI160-MoCap protocol with fixed mounting and toe-marker reference.

Future work should focus on event-timing checkpoint selection, fast-walking and long-trial robustness, improved ZUPT selection, stance-attitude correction, vertical endpoint constraints, and calibration-free toe-offset estimation. Hardware work should also quantify BLE reliability, onboard buffering, CSV logging, battery life, enclosure stability, and
repeated | shoe-mounting | consistency | before | applied
deployment is claimed.

10

VII. CONCLUSION
This study evaluated two separate parts of a low-cost wearable MTC workflow: an IMU-based MTC algorithm validated using SPC2019 MoCap data, and a BMI160/XIAO prototype verified at waveform level. The strict-nested algorithm was validated on 12 SPC2019 participants, producing 7142 matched strides with a bias of -3.000 mm, MAE of 8.638 mm, RMSE of 11.401 mm, and Pearson correlation of r = 0.674. This shows millimeter-scale agreement under controlled conditions, particularly during normal-speed walking.

However, accuracy remained dependent on event timing, drift correction, ZUPT selection, gravity removal, sensor-to-toe geometry, and MoCap-referenced toe-offset calibration. Fast and long mixed-speed trials were more error-sensitive, and two participants were excluded because strict ML event recovery failed before calibration.

The BMI160/XIAO prototype captured repeatable gyroscope-norm gait waveforms and speed-dependent rhythm changes, supporting signal plausibility only. Because the BMI160 recordings were not synchronized with MoCap, the prototype is not yet validated for MTC accuracy. Overall, the work should be positioned as a validated offline algorithm with a signal-plausible low-cost prototype, with synchronized BMI160-MoCap testing required as the next step.

| REFERENCES
[1] G. Delfi, A. Al Bochi, and T. Dutta, “A scoping review on minimum foot clearance measurement: Sensing modalities,” Int. J. Environ. Res. Public Health, vol. 18, no. 20, Art. no. 10848, Oct. 2021, doi: 10.3390/ijerph182010848.
[2] M. Benoussaad, B. Sijobert, K. Mombaur, and C. Azevedo Coste, “Robust foot clearance estimation based on the integration of foot-mounted IMU acceleration data,” Sensors, vol. 16, no. 1, Art. no. 12, Dec. 2015, doi: 10.3390/s16010012.
[3] B. Mariani, S. Rochat, C. J. Büla, and K. Aminian, “Heel and toe clearance estimation for gait analysis using wireless inertial sensors,” IEEE Trans. Biomed. Eng., vol. 59, no. 11, pp. 3162-3168, Nov. 2012, doi: 10.1109/TBME.2012.2216263.
[4] K. H. Fehr, J. N. Bartloff, Y. Wang, S. Hetzel, and P. G. Adamczyk, “Estimation of minimum foot clearance using a single foot-mounted inertial sensor and personalized foot geometry scan,” Sci. Rep., vol. 14, Art. no. 13640, Jun. 2024, doi: 10.1038/s41598-024-63124-6.
[5] R. Romijnders, E. Warmerdam, C. Hansen, G. Schmidt, and W. Maetzler, “A deep learning approach for gait event detection from a single shank-worn IMU: Validation in healthy and neurological cohorts,” Sensors, vol. 22, no. 10, Art. no. 3859, May 2022, doi: 10.3390/s22103859.
[6] MaD Lab FAU, “SensorPositionComparison2019 - Full mocap reference data set with 6 sensors per foot,” gaitmapdatasets documentation. Accessed: May 27, 2026. [Online].

Available: https://mad-lab-fau.github.io/gaitmapdatasets/auto_examples/sensor_position_comparison_2019.ht ml

[7] A. Küderle, N. Roth, J. Zlatanovic, M. Zrenner, B. M. Eskofier, and F. Kluge, “The placement of foot-mounted IMU sensors does affect the accuracy of spatial parameters during regular walking,” PLOS ONE, vol. 17, no. 6, Art. no. e0269567, Jun. 2022, doi: 10.1371/journal.pone.0269567.
[8] Bosch Sensortec GmbH, BMI160 Small, Low Power Inertial Measurement Unit Data Sheet, Rev. 1.0, Nov. 2020. Accessed: May 25, 2026. [Online]. Available: https://www.boschsensortec.com/media/boschsensortec/downloads/datasheets/bst -bmi160-ds000.pdf
[9] Seeed Studio, “Getting started with Seeed Studio XIAO nRF52840 Series,” Seeed Studio Wiki, Apr. 2025. Accessed: May 25, 2026. [Online]. Available: https://wiki.seeedstudio.com/XIAO_BLE/
[10] L. Blanco-Coloma et al., “Validation of inertial measurement units based on waveform similarity assessment against a photogrammetry system for gait kinematic analysis,” Front. Bioeng. Biotechnol., vol. 12, Art. no. 1449698, Aug. 2024, doi: 10.3389/fbioe.2024.1449698.
[11] F. Gustafsson, “Determining the initial states in forwardbackward filtering,” IEEE Trans. Signal Process., vol. 44, no. 4, pp. 988-992, Apr. 1996, doi: 10.1109/78.492552.
[12] I. Skog, P. Händel, J.-O. Nilsson, and J. Rantakokko, “Zero-velocity detection - An algorithm evaluation,” IEEE Trans. Biomed. Eng., vol. 57, no. 11, pp. 2657-2666, Nov. 2010, doi: 10.1109/TBME.2010.2060723.
[13] S. O. H. Madgwick, “An efficient orientation filter for inertial and inertial/magnetic sensor arrays,” Internal Rep., Univ. Bristol, Bristol, U.K., Apr. 2010.
[14] H. Sakoe and S. Chiba, “Dynamic programming algorithm optimization for spoken word recognition,” IEEE Trans. Acoust., Speech, Signal Process., vol. ASSP-26, no. 1, pp. 43-49, Feb. 1978, doi: 10.1109/TASSP.1978.1163055.

ACKNOWLEDGMENT
OpenAI GPT-5.5 Thinking was used to assist with writing refinement, clarity, formatting, and understanding technical concepts from the cited references. All research decisions, analysis, results, citations, and final content were reviewed and approved by the author.

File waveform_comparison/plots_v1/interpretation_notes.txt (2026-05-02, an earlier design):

Raw visual comparison notes:\n- Main fair comparison: acceleration norm and gyroscope norm.\n- Axis-wise plots are qualitative only because casing axes and gaitmap coordinate axes may differ.\n- Your BMI160 acceleration was converted from g to m/s^2.\n- Your BMI160 gyroscope was converted from deg/s to rad/s.\n- Dataset target: participant 4d91, normal_10, right side, r_instep.\n- For professor review: show 03_acc_norm_comparison.png, 04_gyr_norm_comparison.png, and 05_zscore_norm_shape_comparison.png first.\n

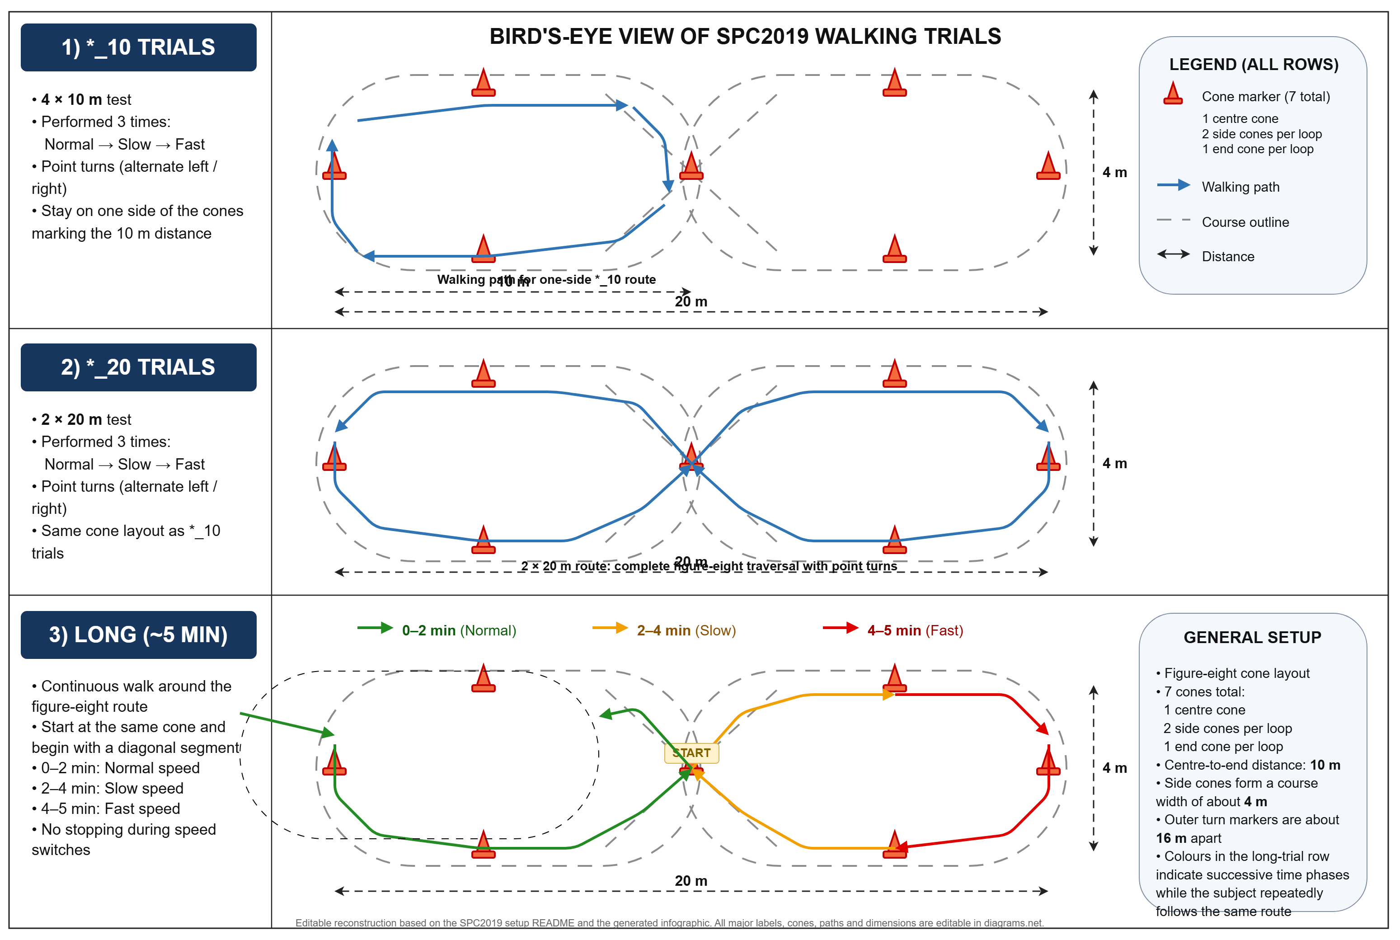
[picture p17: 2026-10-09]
docs/figures/spc2019_walking_trials.png

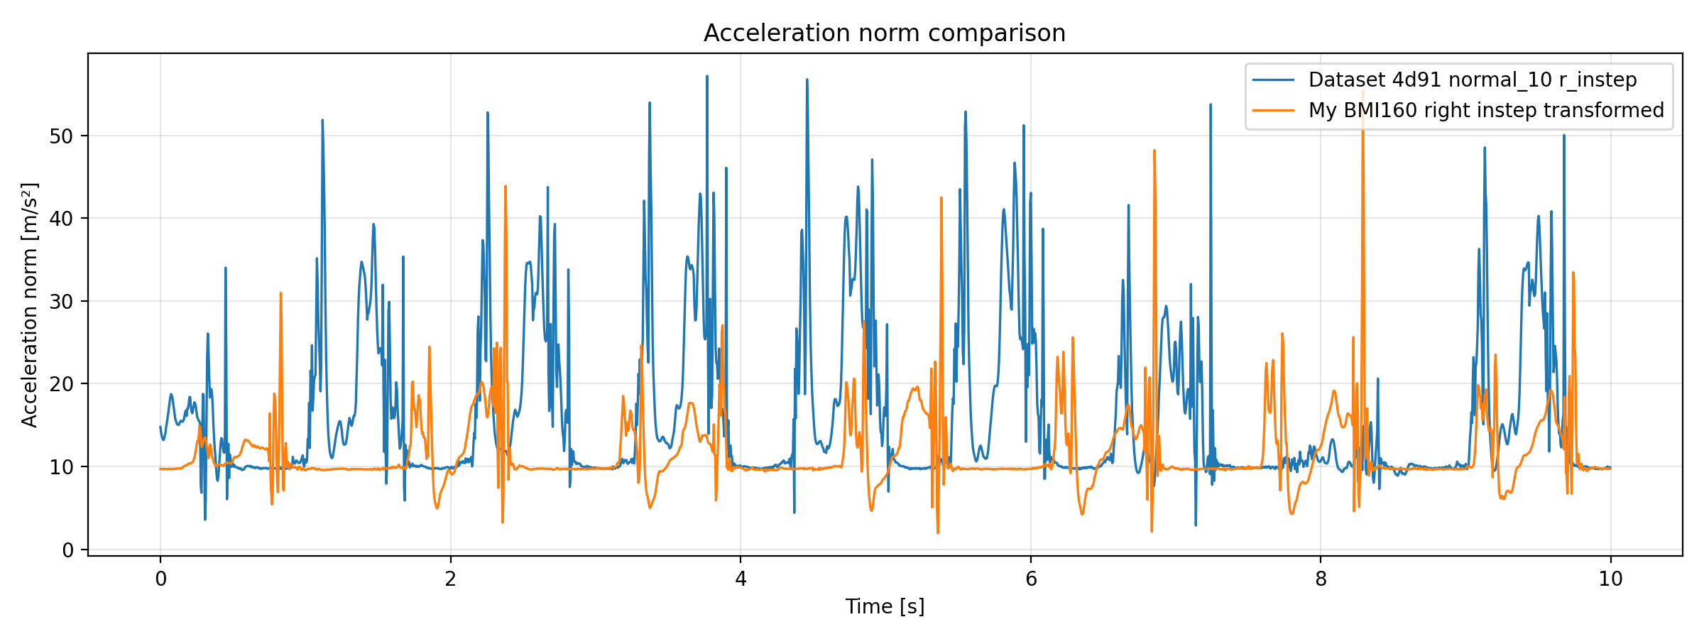
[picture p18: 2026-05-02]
waveform_comparison/plots/03_acc_norm_comparison.png

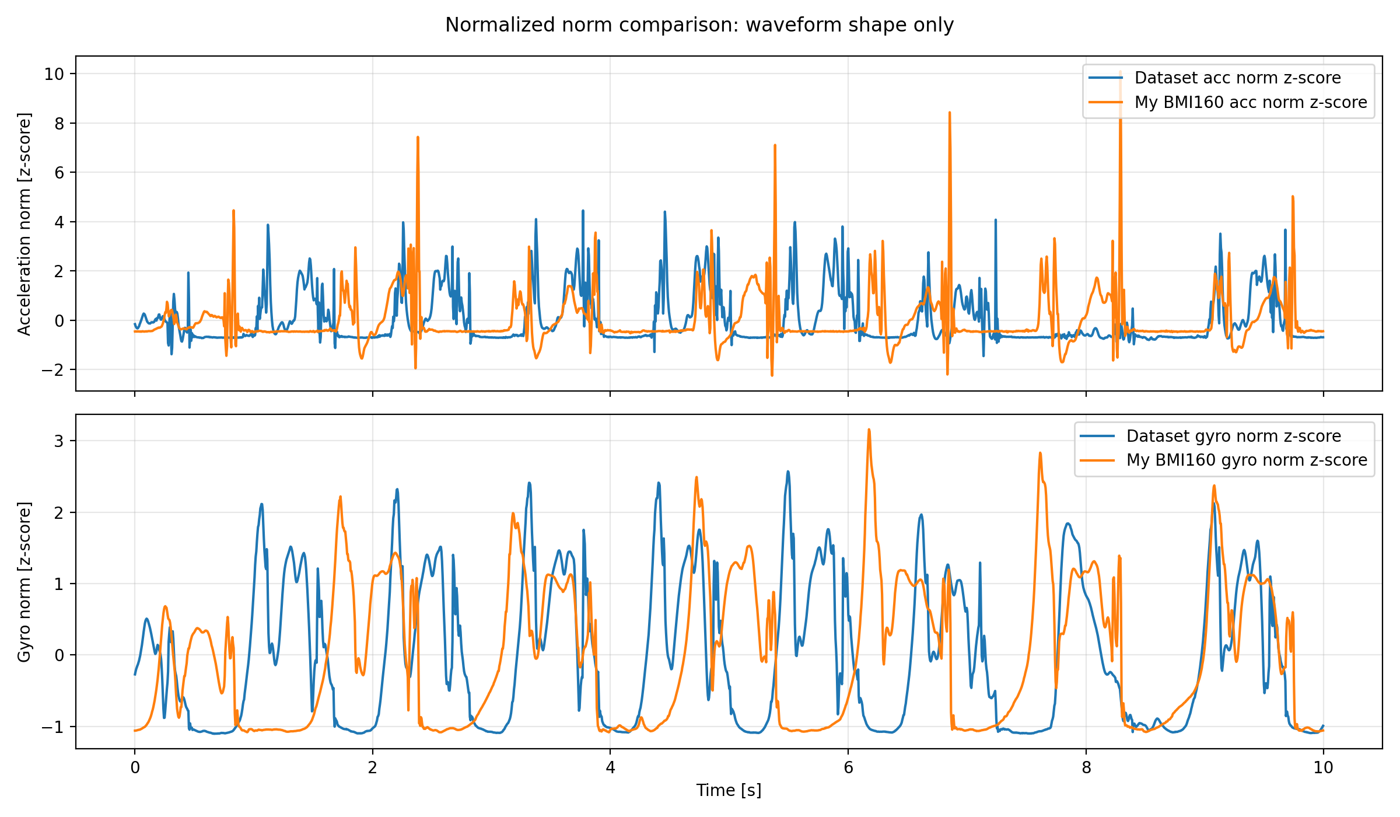
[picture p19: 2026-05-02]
waveform_comparison/plots/05_zscore_norm_shape_comparison.png

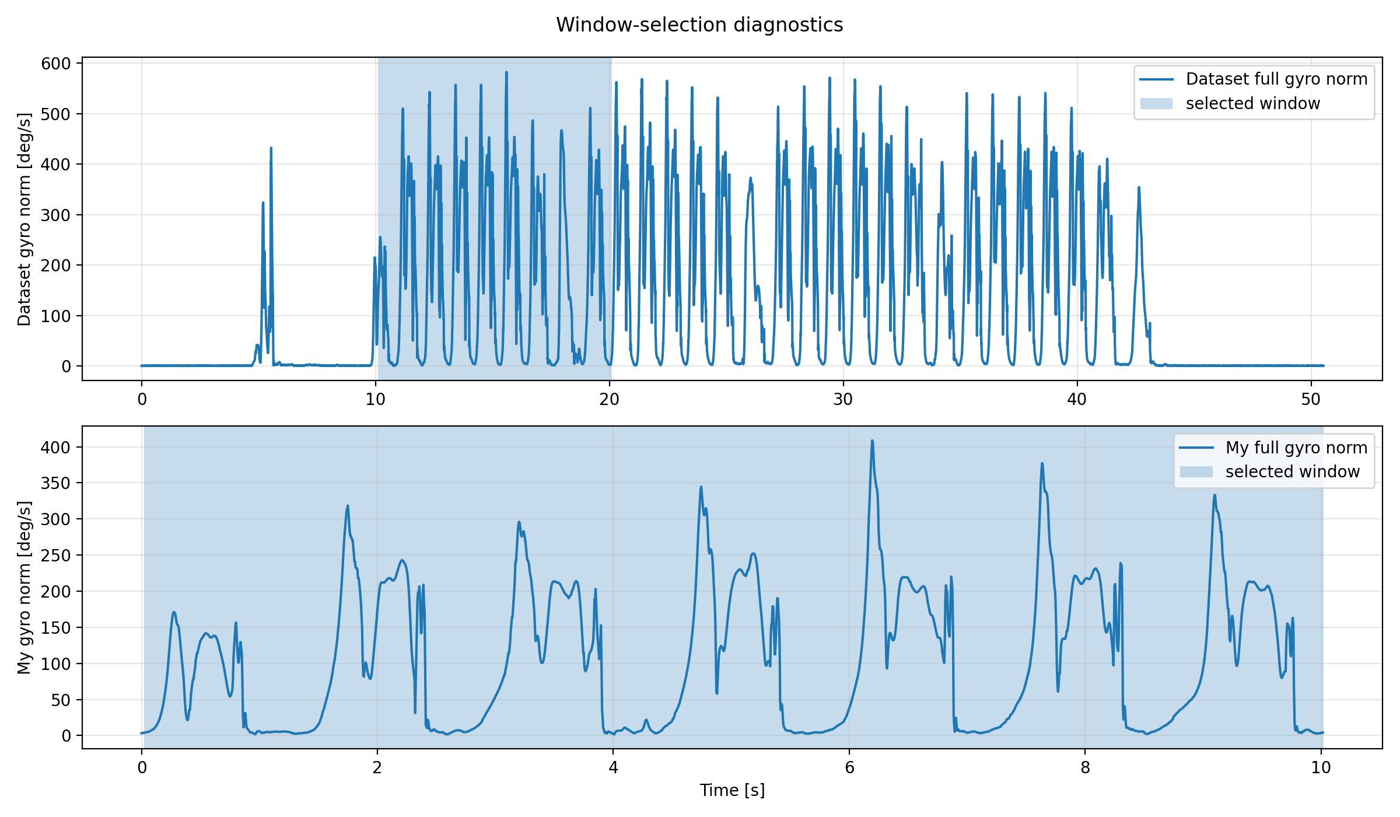
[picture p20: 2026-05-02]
waveform_comparison/plots/00_window_selection_diagnostics.png

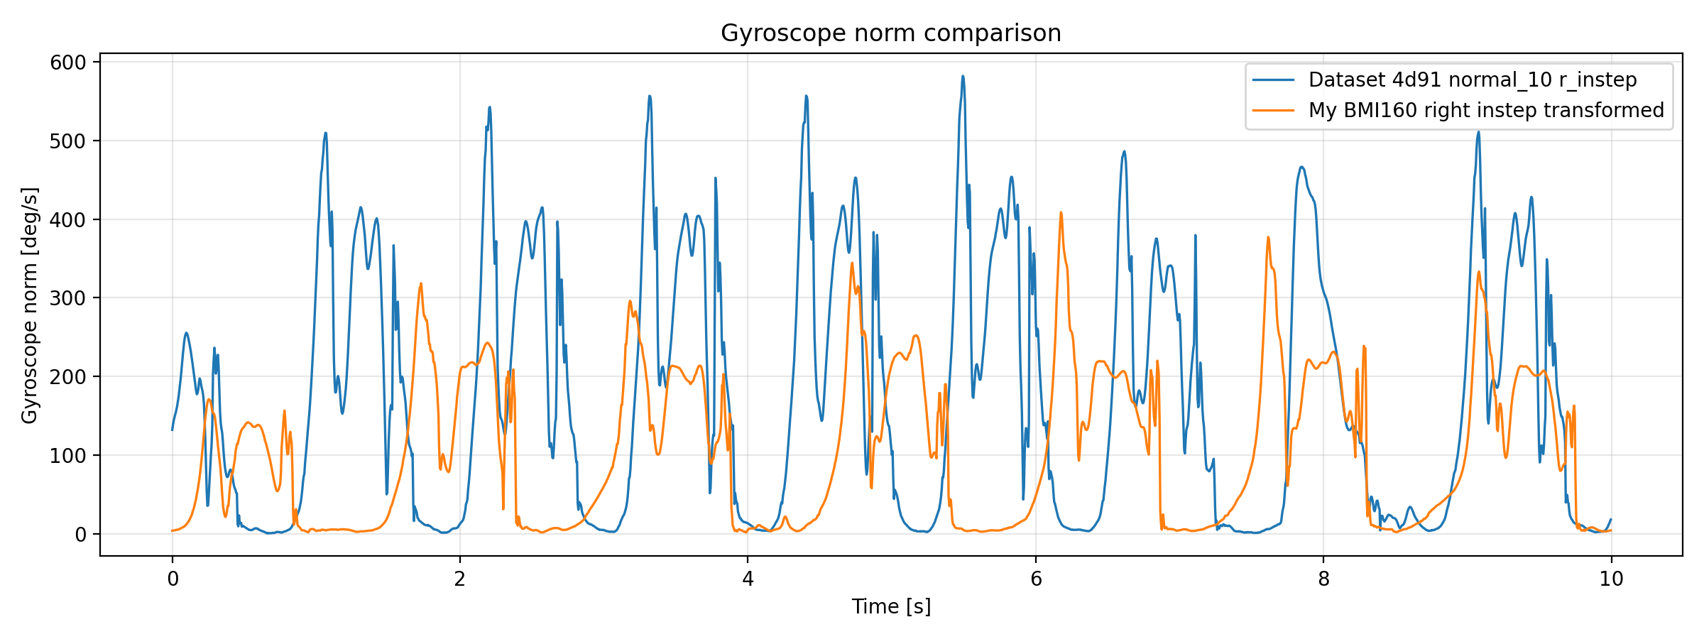
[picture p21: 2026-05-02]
waveform_comparison/plots/04_gyr_norm_comparison_degps.png

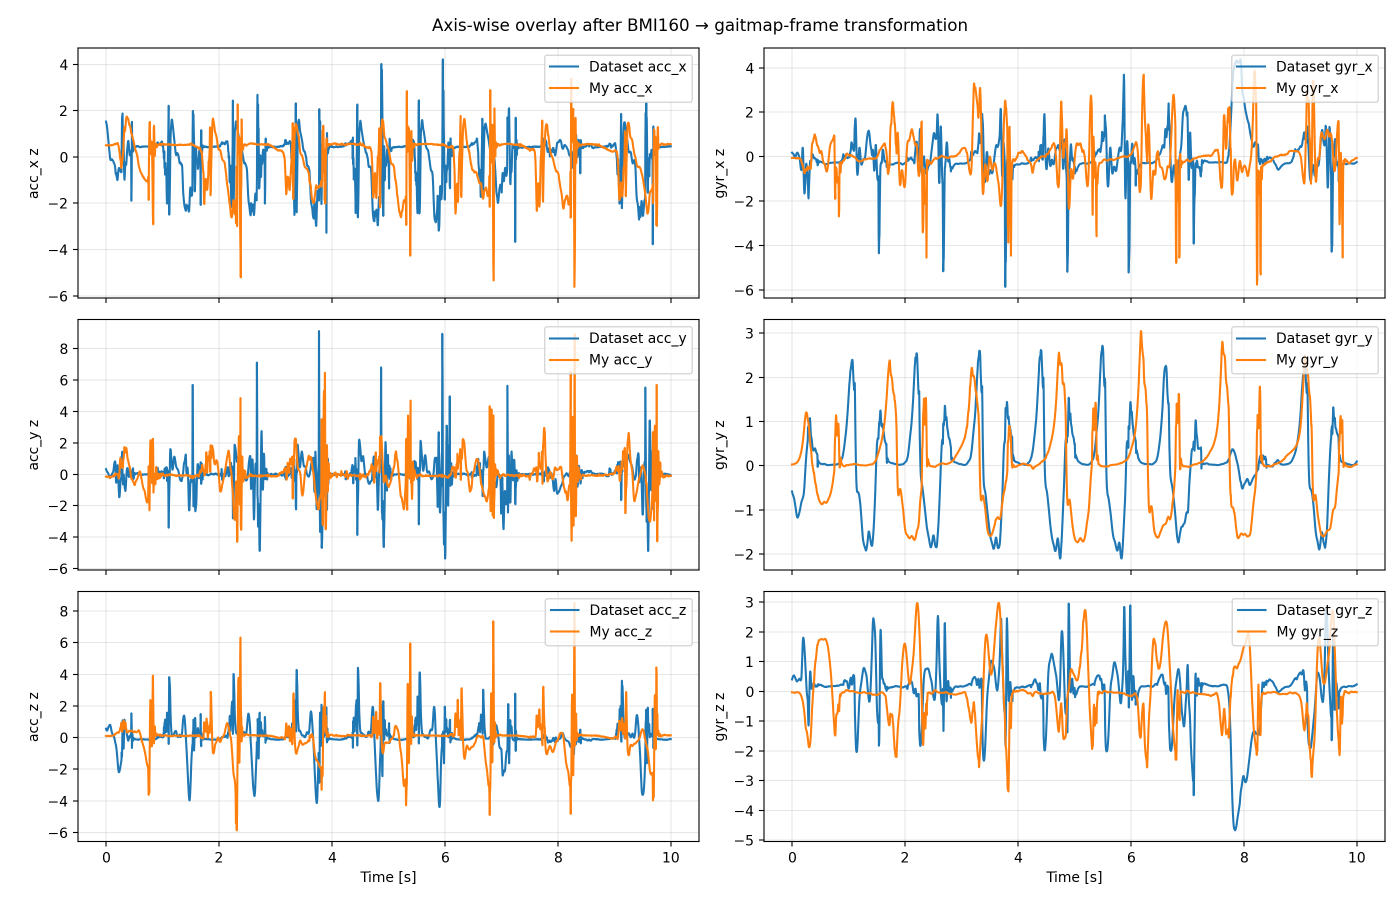
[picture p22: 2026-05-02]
waveform_comparison/plots/06_axis_overlay_gaitmap_frame.png

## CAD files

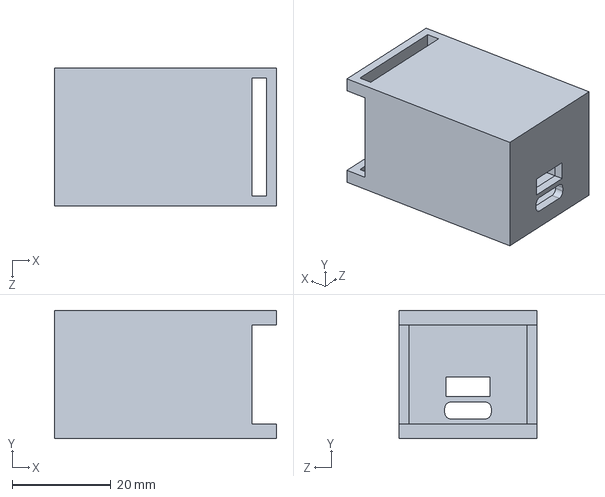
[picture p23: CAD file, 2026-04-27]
hardware/enclosure_cad/V7/Shell_Part_V7.SLDPRT
45.0 x 26.0 x 28.0 mm

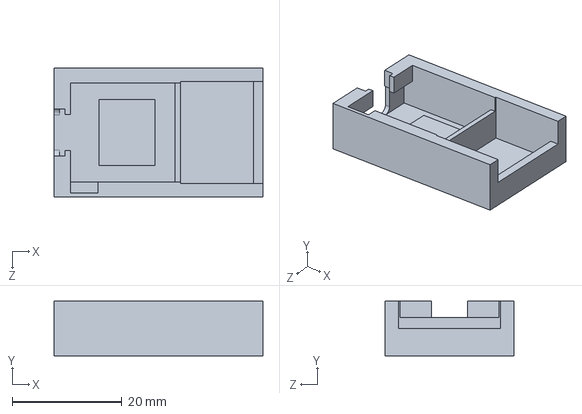
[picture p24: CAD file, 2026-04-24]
hardware/enclosure_cad/V7/Bottom_Part_V7.SLDPRT
38.0 x 10.0 x 23.5 mm

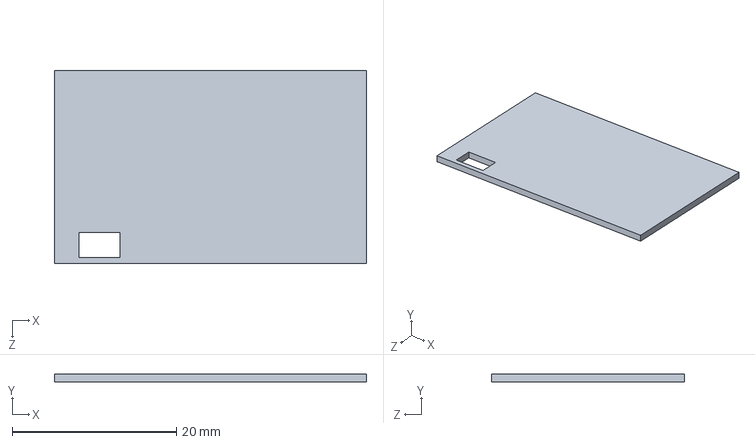
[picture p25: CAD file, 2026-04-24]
hardware/enclosure_cad/V7/Top_Part_V7.SLDPRT
38.0 x 1.00 x 23.5 mm

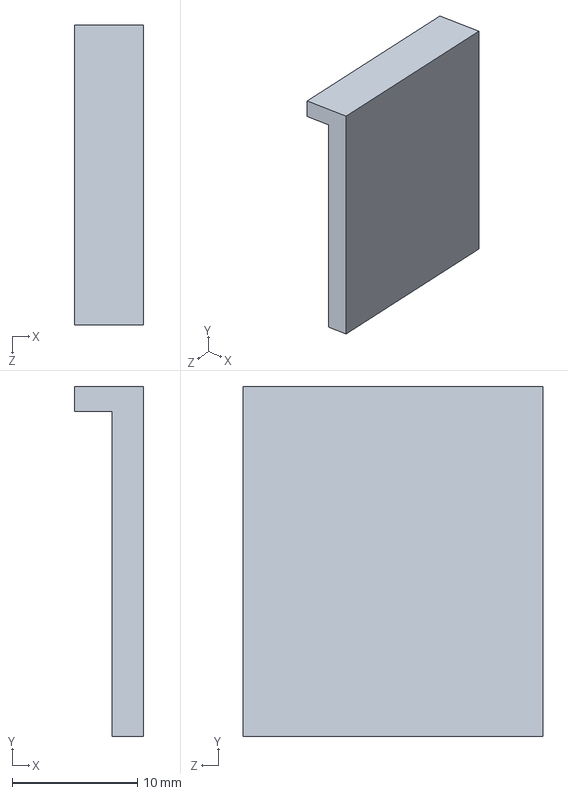
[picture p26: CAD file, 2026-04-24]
hardware/enclosure_cad/V7/Sliding_Door_Part_V7.SLDPRT
5.50 x 28.0 x 24.0 mm

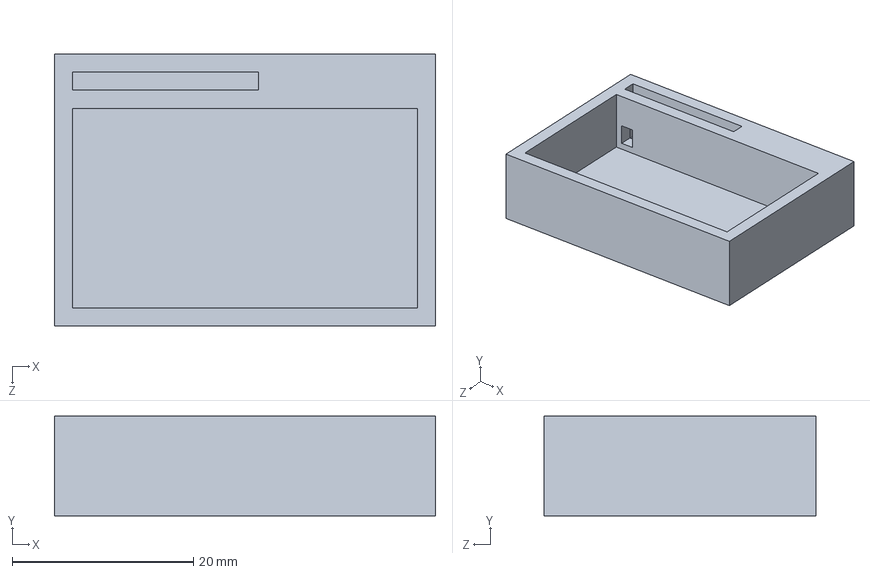
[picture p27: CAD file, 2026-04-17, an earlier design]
hardware/enclosure_cad/V1/Top_Part.SLDPRT
42.0 x 11.0 x 30.0 mm

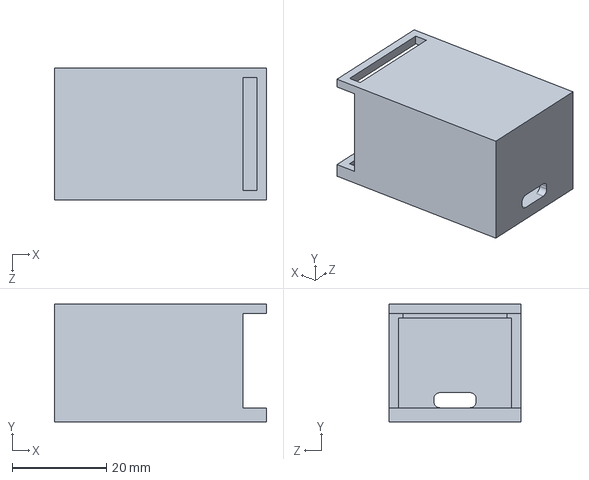
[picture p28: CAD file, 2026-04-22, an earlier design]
hardware/enclosure_cad/V2/Shell_Part.SLDPRT
45.0 x 25.0 x 28.0 mm

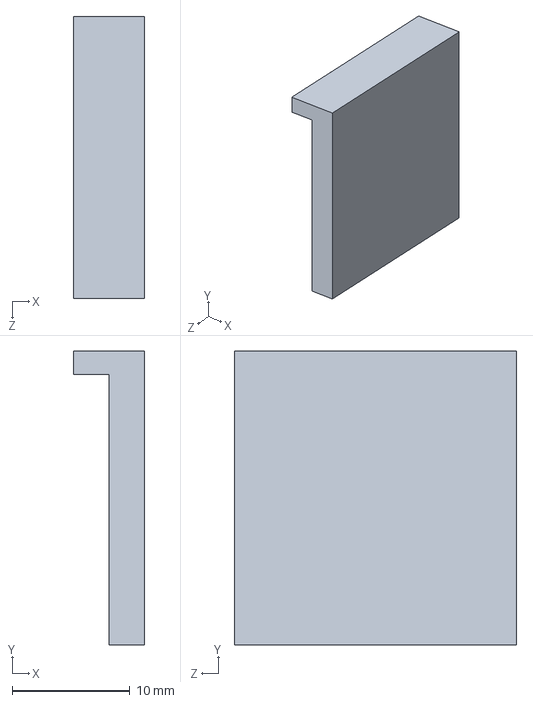
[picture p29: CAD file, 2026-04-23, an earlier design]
hardware/enclosure_cad/V3/Sliding_Door_Part_V3.SLDPRT
6.00 x 25.0 x 24.0 mm

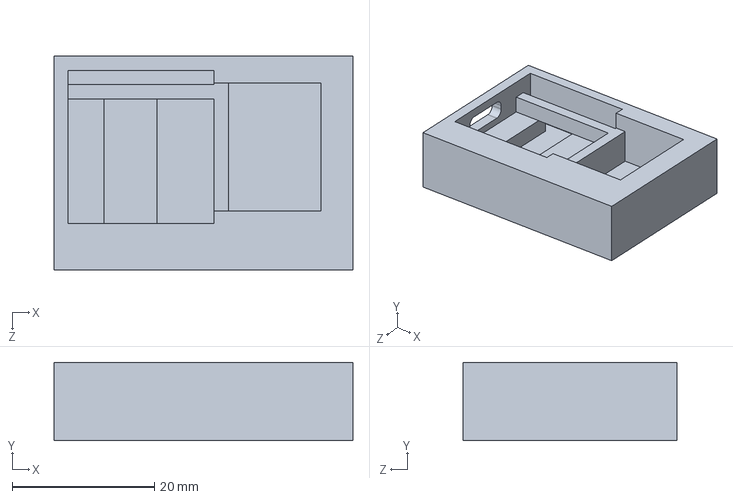
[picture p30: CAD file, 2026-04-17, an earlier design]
hardware/enclosure_cad/V1/Bottom_Part.SLDPRT
42.0 x 11.0 x 30.0 mm

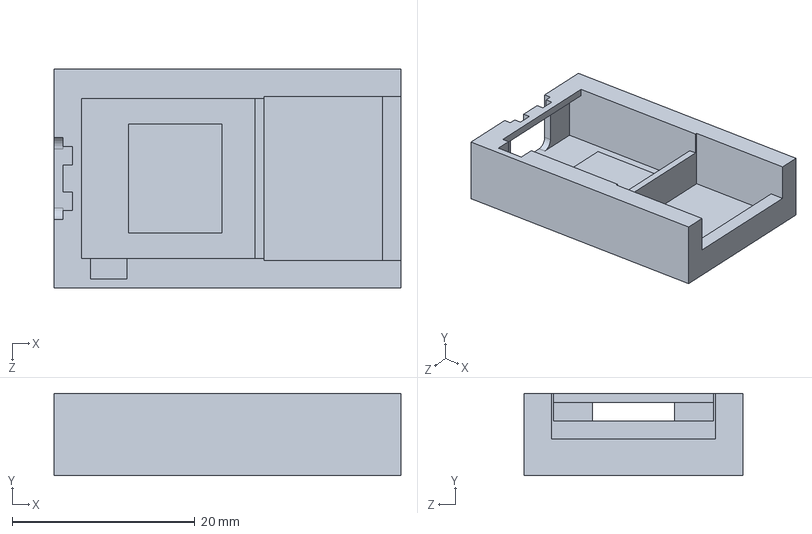
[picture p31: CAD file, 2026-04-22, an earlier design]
hardware/enclosure_cad/V2/Bottom_Part_V2.SLDPRT
38.0 x 9.00 x 24.0 mm

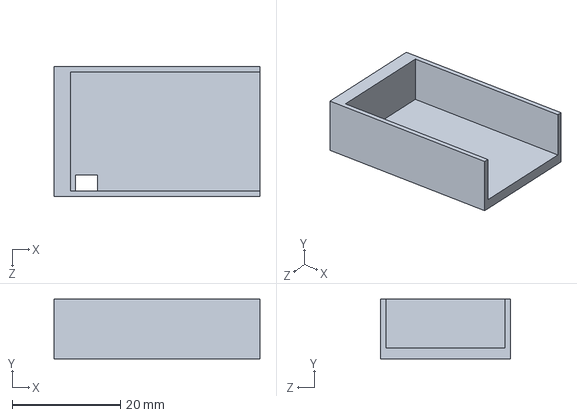
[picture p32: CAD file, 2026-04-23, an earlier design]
hardware/enclosure_cad/V3/Top_Part_V3.SLDPRT
38.0 x 11.0 x 24.0 mm

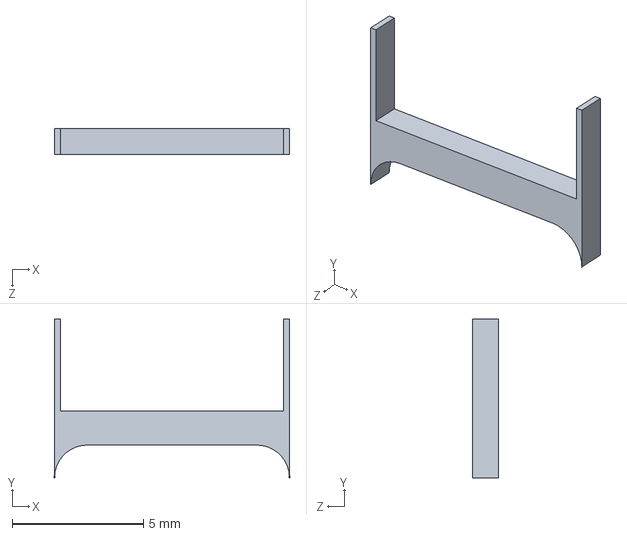
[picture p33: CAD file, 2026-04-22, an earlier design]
hardware/enclosure_cad/V2/Switch_Fit_Part.SLDPRT
8.94 x 6.04 x 1.00 mm

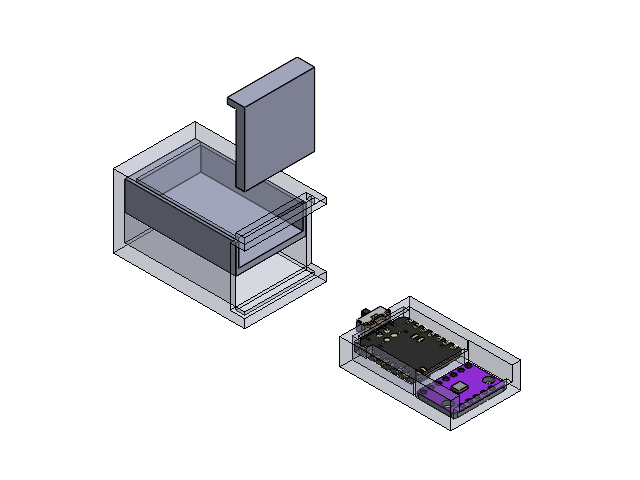
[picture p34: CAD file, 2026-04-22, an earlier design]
hardware/enclosure_cad/V2/Casing.SLDASM
Shell_Part
Bottom_Part_V2
Top_Part_V2
Sliding_Door_Part
BOSS-EXTRUDE14_8_.step
BOSS-EXTRUDE7_4_.step
BOSS-EXTRUDE7_3_.step
BOSS-EXTRUDE14_4_.step
BOSS-EXTRUDE14_2_.step
BOSS-EXTRUDE14_11_.step
BOSS-EXTRUDE7_7_.step
BOSS-EXTRUDE14_9_.step
BOSS-EXTRUDE14_3_.step
BOSS-EXTRUDE14_7_.step
MIRROR2.step
BOSS-EXTRUDE14_5_.step
BOSS-EXTRUDE14_12_.step
BOSS-EXTRUDE7_8_.step
BOSS-EXTRUDE7_1_.step
BOSS-EXTRUDE14_10_.step
BOSS-EXTRUDE7_9_.step
BOSS-EXTRUDE14_6_.step
CHAMFER9.step
BOSS-EXTRUDE14_1_.step
BOSS-EXTRUDE7_6_.step
BOSS-EXTRUDE7_2_.step
CUT-EXTRUDE5.step
BOSS-EXTRUDE7_5_.step
Body.step
Pins.step
CAP.step x 2
ANT1.step
Silkscreen.step
CAP 3.step
LED.step
USR.step
PCB (1)-0.step
PCB (1)-1.step
PCB (1)-2.step
PCB (1)-3.step
PCB (1)-4.step
PCB (1)-5.step
PCB (1)-6.step
PCB (1)-7.step
PCB (1)-8.step
PCB (1)-9.step
PCB (1)-10.step
PCB (1)-11.step
PCB (1)-12.step
PCB (1)-13.step
PCB (1)-14.step
PCB (1)-15.step
MSM261D3526H1CPM-16.step
MSM261D3526H1CPM-17.step
MSM261D3526H1CPM-18.step
MSM261D3526H1CPM-19.step
MSM261D3526H1CPM-20.step
MSM261D3526H1CPM-21.step
MSM261D3526H1CPM-22.step
MSM261D3526H1CPM-23.step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

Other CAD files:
hardware/enclosure_cad/V4/Top_Part_V4.SLDPRT
hardware/enclosure_cad/V5/Bottom_Part_V5.SLDPRT
hardware/enclosure_cad/V6/Bottom_Part_V6.STL
hardware/enclosure_cad/V4/Bottom_Part_V4.SLDPRT
hardware/enclosure_cad/V5/Top_Part_V5.STL
hardware/enclosure_cad/V6/Shell_Part_V6.SLDPRT
hardware/enclosure_cad/V2/Bottom_Part_V2.STL
hardware/enclosure_cad/V2/Shell_Part.STL
hardware/enclosure_cad/V2/Sliding_Door_Part.SLDPRT
hardware/enclosure_cad/V2/Sliding_Door_Part.STL
hardware/enclosure_cad/V2/Switch_Fit_Part.STL
hardware/enclosure_cad/V2/Top_Part_V2.SLDPRT
hardware/enclosure_cad/V2/Top_Part_V2.STL
hardware/enclosure_cad/V3/Bottom_Part_V3.SLDPRT
hardware/enclosure_cad/V3/Bottom_Part_V3.STL
hardware/enclosure_cad/V3/Shell_Part_V3t.SLDPRT
hardware/enclosure_cad/V3/Shell_Part_V3t.STL
hardware/enclosure_cad/V3/Sliding_Door_Part_V3.STL
hardware/enclosure_cad/V3/Top_Part_V3.STL
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

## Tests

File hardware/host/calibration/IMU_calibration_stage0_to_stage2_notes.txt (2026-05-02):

IMU CALIBRATION PIPELINE NOTES — STAGE 0 TO STAGE 2

Firmware used for all recording:
- GyroAndAccel_XIAO_RAM_100Hz_CSV_DUMP_ACK.ino
- Same Arduino firmware is used for Stage 0, Stage 2, and walking trials.

Main rule:
- Stage 0 and Stage 1 are for the container/sensor calibration.
- Stage 2 is for the shoe-mounted session calibration.
- Redo Stage 2 whenever the casing is removed, repositioned, re-strapped, or mounted on a different shoe.

STAGE 0 — Face auto-axis detector
Purpose:
- Identify which physical casing face corresponds to x_plus, x_minus, y_plus, y_minus, z_plus, z_minus.

When to run:
- After the BMI160 is fixed inside the casing/container.
- Run again if the board position inside the casing changes.

How to run:
python stage0_face_auto_axis_detector_ROBUST.py

What to do:
- Follow the prompts for Front, Back, Top, Bottom, Left, Right.
- Keep the casing completely still for each face recording.
- The script auto-renames files like:
  Front_x_plus.csv
  Back_x_minus.csv
  Top_z_plus.csv

Good result:
- Each face saves a clean CSV.
- No missing sequence values.
- You get one file for each:
  x_plus, x_minus, y_plus, y_minus, z_plus, z_minus.

STAGE 1 — Container accelerometer calibration
Purpose:
- Calculate accelerometer offset and scale correction for the sensor inside the casing.
- Uses the six files from Stage 0.

When to run:
- After Stage 0.
- Run once for the casing setup.
- Redo only if the sensor board moves inside the casing.

How to run:
python stage1_container_accel_calibration.py six ^
  --x-plus imu_face_calibration\Front_x_plus.csv ^
  --x-minus imu_face_calibration\Back_x_minus.csv ^
  --y-plus imu_face_calibration\Left_y_plus.csv ^
  --y-minus imu_face_calibration\Right_y_minus.csv ^
  --z-plus imu_face_calibration\Top_z_plus.csv ^
  --z-minus imu_face_calibration\Bottom_z_minus.csv ^
  --out stage1_container_accel_calibration.json

Important:
- Use the axis label in the filename, not the face name.
- Example: a file ending in _x_plus.csv goes to --x-plus.

Good result:
- Quality: PASS
- Output file:
  stage1_container_accel_calibration.json

Current Stage 1 result:
- ax offset = 0.061630 g
- ay offset = -0.057616 g
- az offset = 0.019411 g
- ax scale = 1.002410
- ay scale = 1.005592
- az scale = 0.988756

STAGE 2 — Shoe-mounted gyro calibration
Purpose:
- Calculate gyroscope zero-rate bias after the casing is mounted on the shoe.
- Also records the mounted gravity direction.

When to run:
- After the casing is mounted on the shoe exactly like the walking setup.
- Run before walking trials.
- Redo if the casing is moved, removed, re-strapped, or shoe changes.

Condition:
- Shoe flat on the floor.
- Completely still.
- Do NOT walk during Stage 2.

How to run:
python stage2_shoe_gyro_calibration.py --stage1-accel-calib stage1_container_accel_calibration.json

Good result:
- Quality: PASS
- Output file:
  stage2_shoe_mounted_session_calibration.json

Current Stage 2 result:
- gx bias = -0.404765 dps
- gy bias = 0.241896 dps
- gz bias = 0.235968 dps
- mounted gravity vector = [-0.440821, -0.005699, 0.897577]
- accel norm = 0.999893 g

AFTER STAGE 2 — Walking trials
Before walking:
- Keep the same casing position and same strap/lace tightness.
- Do not move the casing after Stage 2.

Use calibration:
- Apply Stage 1 accelerometer correction.
- Apply Stage 2 gyroscope bias correction.

Acceptance rule:
- Only accept recordings where:
  SEQ CHECK = PASS
  missed = 0
  read_failures = 0
  bad/clipped lines = 0

Quick memory:
- Stage 0 = find casing face to sensor axis.
- Stage 1 = calibrate accelerometer inside casing.
- Stage 2 = calibrate gyro after mounting on shoe.

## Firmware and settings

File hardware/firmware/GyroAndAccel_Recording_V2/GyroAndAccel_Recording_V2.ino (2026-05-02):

#include <Arduino.h>
#include <Wire.h>
#include <Adafruit_TinyUSB.h>
#include <bluefruit.h>

/*
  XIAO nRF52840 + external BMI160 over I2C

  Reliable method:
    1) Record raw IMU samples into XIAO RAM at 200 Hz.
    2) Python sends stop.
    3) XIAO dumps CSV in chunks.
    4) Python verifies every seq in the chunk.
    5) Python sends ACK,<next_seq> if complete, or NACK,<chunk_start> if incomplete.
    6) XIAO only sends the next chunk after ACK.

  This solves the previous problem where Python saved fewer CSV rows than the XIAO recorded.

  Python commands over BLE UART:
    start           -> start RAM recording
    stop            -> stop RAM recording and begin reliable CSV dump
    ACK,<next_seq>  -> Python confirms chunk received completely
    NACK,<seq>      -> Python requests resend from seq/chunk start
    cancel          -> cancel recording/dump
    status          -> print current state
*/

BLEUart bleuart;

static const char* DEVICE_NAME = "XIAO_BATTERY";

// Your I2C scanner showed BMI160 at 0x69. If it changes, set this to 0x68.
static const uint8_t BMI160_ADDR = 0x69;

// BMI160 registers
static const uint8_t REG_CHIP_ID    = 0x00;
static const uint8_t REG_GYR_DATA   = 0x0C;  // burst from 0x0C gives gyro then accel
static const uint8_t REG_ACC_CONF   = 0x40;
static const uint8_t REG_ACC_RANGE  = 0x41;
static const uint8_t REG_GYR_CONF   = 0x42;
static const uint8_t REG_GYR_RANGE  = 0x43;
static const uint8_t REG_CMD        = 0x7E;

static const uint8_t CMD_SOFTRESET  = 0xB6;
static const uint8_t CMD_ACC_NORMAL = 0x11;
static const uint8_t CMD_GYR_NORMAL = 0x15;

// BMI160 config: 200 Hz, normal/OSR4 bandwidth, +/-16g, +/-2000 dps
// Register values from BMI160 datasheet:
//   ACC_RANGE 0x03=2g, 0x05=4g, 0x08=8g, 0x0C=16g
//   GYR_RANGE 0x00=2000dps, 0x01=1000dps, 0x02=500dps, 0x03=250dps, 0x04=125dps
static const uint8_t ACC_CONF_200HZ     = 0x29;
static const uint8_t ACC_RANGE_16G      = 0x0C;
static const uint8_t GYR_CONF_200HZ     = 0x29;
static const uint8_t GYR_RANGE_2000DPS  = 0x00;

// Scale factors for CSV output.
// Current config:
//   +/-16g     -> 2048 LSB/g
//   +/-2000dps -> 16.4 LSB/(deg/s)
static const float ACC_LSB_PER_G   = 2048.0f;
static const float GYR_LSB_PER_DPS = 16.4f;

static const uint16_t SAMPLE_HZ = 200;
static const uint32_t SAMPLE_PERIOD_US = 1000000UL / SAMPLE_HZ;

// 6000 samples = 30 seconds at 200 Hz.
// sizeof(ImuSample) is normally 16 bytes, so this uses about 96 KB RAM.
// Keeping 6000 samples is safer for the XIAO nRF52840 BLE stack than increasing to 12000.
static const uint16_t MAX_SAMPLES = 6000;

// Reliable CSV dump settings.
// 20 rows per chunk keeps the CSV readable and limits retransmission size.
static const uint16_t CHUNK_LINES = 20;
static const uint32_t ACK_TIMEOUT_MS = 3000;
static const uint8_t MAX_CHUNK_RETRIES = 20;

// Conservative line-burst throttle inside each chunk.
static const uint8_t FLUSH_EVERY_LINES = 2;
static const uint8_t FLUSH_DELAY_MS = 2;

// Set 1 only when debugging over USB Serial. Leaving it 0 makes dump faster.
static const uint8_t SERIAL_ECHO_CSV = 0;

struct ImuSample {
  uint32_t t_ms;
  int16_t ax;
  int16_t ay;
  int16_t az;
  int16_t gx;
  int16_t gy;
  int16_t gz;
};

ImuSample samples[MAX_SAMPLES];

bool bmi_ok = false;
bool recording = false;
bool dumping = false;
bool waiting_for_ack = false;

uint32_t record_start_ms = 0;
uint32_t next_sample_us = 0;
uint16_t sample_count = 0;
uint16_t dump_index = 0;
uint32_t missed_samples = 0;
uint32_t read_failures = 0;

uint16_t current_chunk_start = 0;
uint16_t current_chunk_end = 0;  // exclusive
uint8_t chunk_retry_count = 0;
uint32_t last_chunk_send_ms = 0;

String cmd_buf = "";

static inline int16_t s16(uint8_t lo, uint8_t hi) {
  return (int16_t)((uint16_t)hi << 8 | lo);
}

bool writeReg(uint8_t reg, uint8_t value) {
  Wire.beginTransmission(BMI160_ADDR);
  Wire.write(reg);
  Wire.write(value);
  return Wire.endTransmission() == 0;
}

bool readRegs(uint8_t reg, uint8_t* buf, size_t len) {
  Wire.beginTransmission(BMI160_ADDR);
  Wire.write(reg);
  if (Wire.endTransmission(false) != 0) return false;

  size_t n = Wire.requestFrom(BMI160_ADDR, (uint8_t)len);
  if (n != len) return false;

  for (size_t i = 0; i < len; i++) {
    buf[i] = Wire.read();
  }
  return true;
}

uint8_t readReg(uint8_t reg) {
  uint8_t v = 0xFF;
  readRegs(reg, &v, 1);
  return v;
}

void flushBle() {
  if (Bluefruit.connected()) {
    bleuart.flushTXD();
  }
}

void bleWriteRaw(const char* text) {
  if (Bluefruit.connected()) {
    bleuart.write((const uint8_t*)text, strlen(text));
  }
}

void sendLine(const String& line) {
  Serial.println(line);
  if (Bluefruit.connected()) {
    String out = line + "\n";
    bleuart.write((const uint8_t*)out.c_str(), out.length());
  }
}

void startAdv() {
  Bluefruit.Advertising.stop();
  Bluefruit.ScanResponse.clearData();
  Bluefruit.Advertising.clearData();

  Bluefruit.Advertising.addFlags(BLE_GAP_ADV_FLAGS_LE_ONLY_GENERAL_DISC_MODE);
  Bluefruit.Advertising.addTxPower();
  Bluefruit.Advertising.addService(bleuart);
  Bluefruit.ScanResponse.addName();

  Bluefruit.Advertising.restartOnDisconnect(true);
  Bluefruit.Advertising.setInterval(32, 244);  // 20 ms fast, 152.5 ms slow
  Bluefruit.Advertising.setFastTimeout(30);
  Bluefruit.Advertising.start(0);
}

bool initBMI160() {
  uint8_t chip = readReg(REG_CHIP_ID);

  String chipMsg = "CHIP_ID=0x";
  if (chip < 16) chipMsg += "0";
  chipMsg += String(chip, HEX);
  chipMsg.toUpperCase();
  sendLine(chipMsg);

  if (chip != 0xD1) {
    sendLine("ERR,BMI160_NOT_DETECTED_CHECK_ADDR_WIRING_EXPECT_0xD1");
    return false;
  }

  writeReg(REG_CMD, CMD_SOFTRESET);
  delay(120);

  writeReg(REG_CMD, CMD_ACC_NORMAL);
  delay(60);
  writeReg(REG_CMD, CMD_GYR_NORMAL);
  delay(120);

  bool ok = true;
  ok &= writeReg(REG_ACC_CONF, ACC_CONF_200HZ);
  ok &= writeReg(REG_ACC_RANGE, ACC_RANGE_16G);
  ok &= writeReg(REG_GYR_CONF, GYR_CONF_200HZ);
  ok &= writeReg(REG_GYR_RANGE, GYR_RANGE_2000DPS);
  delay(50);

  if (!ok) {
    sendLine("ERR,BMI160_CONFIG_WRITE_FAILED");
    return false;
  }

  sendLine("BMI160_READY,200Hz,I2C_400kHz,ACC_16G,GYR_2000DPS");
  sendLine("BMI160_REGS,ACC_CONF=0x" + String(readReg(REG_ACC_CONF), HEX) +
           ",ACC_RANGE=0x" + String(readReg(REG_ACC_RANGE), HEX) +
           ",GYR_CONF=0x" + String(readReg(REG_GYR_CONF), HEX) +
           ",GYR_RANGE=0x" + String(readReg(REG_GYR_RANGE), HEX));
  return true;
}

bool readRaw(int16_t& ax, int16_t& ay, int16_t& az,
             int16_t& gx, int16_t& gy, int16_t& gz) {
  uint8_t b[12];
  if (!readRegs(REG_GYR_DATA, b, 12)) return false;

  gx = s16(b[0], b[1]);
  gy = s16(b[2], b[3]);
  gz = s16(b[4], b[5]);
  ax = s16(b[6], b[7]);
  ay = s16(b[8], b[9]);
  az = s16(b[10], b[11]);
  return true;
}

void captureOneSample() {
  if (sample_count >= MAX_SAMPLES) {
    missed_samples++;
    return;
  }

  ImuSample& s = samples[sample_count];

  if (!readRaw(s.ax, s.ay, s.az, s.gx, s.gy, s.gz)) {
    read_failures++;
    missed_samples++;
    return;
  }

  s.t_ms = millis() - record_start_ms;
  sample_count++;
}

void startRecording() {
  if (!bmi_ok) {
    sendLine("ERR,BMI160_NOT_READY");
    flushBle();
    return;
  }
  if (recording) {
    sendLine("ERR,ALREADY_RECORDING");
    flushBle();
    return;
  }
  if (dumping) {
    sendLine("ERR,DUMP_IN_PROGRESS");
    flushBle();
    return;
  }

  sample_count = 0;
  dump_index = 0;
  missed_samples = 0;
  read_failures = 0;

  current_chunk_start = 0;
  current_chunk_end = 0;
  chunk_retry_count = 0;
  waiting_for_ack = false;

  record_start_ms = millis();
  next_sample_us = micros();
  recording = true;

  sendLine("STREAM_STARTED,200Hz,RAM_THEN_CHUNKED_CSV_ACK");
  flushBle();
}

void finishDump() {
  dumping = false;
  waiting_for_ack = false;

  String stopped = "STREAM_STOPPED," + String(sample_count) +
                   " samples,missed=" + String(missed_samples) +
                   ",read_failures=" + String(read_failures);
  sendLine(stopped);
  flushBle();
  delay(20);

  // Repeat CSV_END a few times because final metadata has no ACK.
  // Python finalizes on the first CSV_END and ignores duplicates.
  sendLine("CSV_END");
  flushBle();
  delay(20);
  sendLine("CSV_END");
  flushBle();
  delay(20);
  sendLine("CSV_END");
  flushBle();
}

void sendCurrentChunk() {
  if (!dumping) return;

  if (current_chunk_start >= sample_count) {
    finishDump();
    return;
  }

  current_chunk_end = current_chunk_start + CHUNK_LINES;
  if (current_chunk_end > sample_count) current_chunk_end = sample_count;

  sendLine("CHUNK_BEGIN," + String(current_chunk_start) + "," + String(current_chunk_end));

  char line[128];
  uint8_t burst_lines = 0;

  for (uint16_t seq = current_chunk_start; seq < current_chunk_end; seq++) {
    const ImuSample& s = samples[seq];

    snprintf(line, sizeof(line),
             "%u,%lu,%.5f,%.5f,%.5f,%.5f,%.5f,%.5f\n",
             seq,
             (unsigned long)s.t_ms,
             s.ax / ACC_LSB_PER_G,
             s.ay / ACC_LSB_PER_G,
             s.az / ACC_LSB_PER_G,
             s.gx / GYR_LSB_PER_DPS,
             s.gy / GYR_LSB_PER_DPS,
             s.gz / GYR_LSB_PER_DPS);

    if (SERIAL_ECHO_CSV) Serial.print(line);
    bleWriteRaw(line);

    burst_lines++;
    if (burst_lines >= FLUSH_EVERY_LINES) {
      flushBle();
      delay(FLUSH_DELAY_MS);
      burst_lines = 0;
    }
  }

  flushBle();
  sendLine("CHUNK_END," + String(current_chunk_start) + "," + String(current_chunk_end));
  flushBle();

  waiting_for_ack = true;
  last_chunk_send_ms = millis();
}

void beginDump() {
  dumping = true;
  waiting_for_ack = false;
  dump_index = 0;
  current_chunk_start = 0;
  current_chunk_end = 0;
  chunk_retry_count = 0;

  sendLine("CSV_BEGIN");
  sendLine("seq,t_ms,ax_g,ay_g,az_g,gx_dps,gy_dps,gz_dps");
  sendLine("DUMP_INFO,total=" + String(sample_count) + ",chunk=" + String(CHUNK_LINES));
  flushBle();
}

void stopRecordingAndDump() {
  if (!recording) {
    if (dumping) sendLine("ERR,ALREADY_DUMPING");
    else sendLine("ERR,NOT_RECORDING");
    flushBle();
    return;
  }

  recording = false;
  beginDump();
}

void cancelRecordingOrDump() {
  recording = false;
  dumping = false;
  waiting_for_ack = false;
  dump_index = 0;
  sample_count = 0;
  sendLine("CANCELLED");
  flushBle();
}

void handleAck(uint16_t next_seq) {
  if (!dumping || !waiting_for_ack) {
    sendLine("ERR,ACK_UNEXPECTED");
    flushBle();
    return;
  }

  if (next_seq == current_chunk_end) {
    dump_index = next_seq;
    current_chunk_start = next_seq;
    waiting_for_ack = false;
    chunk_retry_count = 0;
    return;
  }

  sendLine("ERR,ACK_MISMATCH,got=" + String(next_seq) +
           ",expected=" + String(current_chunk_end));
  flushBle();
}

void handleNack(uint16_t resend_seq) {
  if (!dumping) {
    sendLine("ERR,NACK_UNEXPECTED");
    flushBle();
    return;
  }

  // Resend the current chunk. If Python sends the exact chunk start, use it.
  // Otherwise clamp to the current chunk start to avoid jumping backwards too far.
  if (resend_seq == current_chunk_start || resend_seq == dump_index) {
    waiting_for_ack = false;
    chunk_retry_count++;
    if (chunk_retry_count > MAX_CHUNK_RETRIES) {
      sendLine("ERR,MAX_RETRIES_ABORT,chunk=" + String(current_chunk_start));
      flushBle();
      dumping = false;
      waiting_for_ack = false;
      return;
    }
    sendCurrentChunk();
  } else {
    sendLine("ERR,NACK_MISMATCH,got=" + String(resend_seq) +
             ",chunk_start=" + String(current_chunk_start));
    flushBle();
  }
}

int valueAfterComma(const String& cmd) {
  int comma = cmd.indexOf(',');
  if (comma < 0) return -1;
  return cmd.substring(comma + 1).toInt();
}

void handleCommand(String cmd) {
  cmd.trim();
  cmd.toLowerCase();
  if (cmd.length() == 0) return;

  Serial.print("RX_CMD=[");
  Serial.print(cmd);
  Serial.println("]");

  // Do not echo RX_CMD into BLE. Python expects a clean parseable stream.

  if (cmd == "start" || cmd == "r") {
    startRecording();
  }
  else if (cmd == "stop") {
    stopRecordingAndDump();
  }
  else if (cmd == "cancel" || cmd == "c") {
    cancelRecordingOrDump();
  }
  else if (cmd.startsWith("ack,")) {
    int v = valueAfterComma(cmd);
    if (v >= 0) handleAck((uint16_t)v);
    else sendLine("ERR,BAD_ACK");
  }
  else if (cmd.startsWith("nack,")) {
    int v = valueAfterComma(cmd);
    if (v >= 0) handleNack((uint16_t)v);
    else sendLine("ERR,BAD_NACK");
  }
  else if (cmd == "status") {
    if (recording) {
      sendLine("STATUS,RECORDING," + String(sample_count) + "/" + String(MAX_SAMPLES));
    } else if (dumping) {
      sendLine("STATUS,DUMPING,chunk=" + String(current_chunk_start) + "-" +
               String(current_chunk_end) + ",dump_index=" + String(dump_index) +
               ",total=" + String(sample_count) +
               ",waiting_ack=" + String(waiting_for_ack ? 1 : 0));
    } else {
      sendLine("STATUS,IDLE,last_samples=" + String(sample_count));
    }
    flushBle();
  }
  else {
    sendLine("ERR,UNKNOWN_CMD");
    flushBle();
  }
}

void readBleCommands() {
  while (bleuart.available()) {
    char c = (char)bleuart.read();
    if (c == '\n' || c == '\r') {
      handleCommand(cmd_buf);
      cmd_buf = "";
    } else {
      cmd_buf += c;
      if (cmd_buf.length() > 60) {
        cmd_buf = "";
        sendLine("ERR,CMD_TOO_LONG");
        flushBle();
      }
    }
  }
}

void setup() {
  Serial.begin(115200);
  delay(1200);

  Wire.begin();
  Wire.setClock(400000);

  // Must be before Bluefruit.begin(). Increases BLE UART bandwidth resources.
  Bluefruit.configPrphBandwidth(BANDWIDTH_MAX);
  Bluefruit.begin();
  Bluefruit.setTxPower(4);
  Bluefruit.setName(DEVICE_NAME);

  // Request short connection interval: min 7.5 ms, max 15 ms.
  // The central device can still reject/adjust it.
  Bluefruit.Periph.setConnInterval(6, 12);

  bleuart.begin();
  bleuart.bufferTXD(true);  // Required for efficient small BLE UART writes.

  startAdv();

  sendLine("XIAO_RAM_100HZ_CHUNKED_CSV_ACK_READY");
  sendLine("Commands: start, stop, ACK,<next_seq>, NACK,<seq>, cancel, status");

  bmi_ok = initBMI160();
  flushBle();
}

void loop() {
  readBleCommands();

  if (recording) {
    uint32_t now_us = micros();

    while ((int32_t)(now_us - next_sample_us) >= 0) {
      next_sample_us += SAMPLE_PERIOD_US;
      captureOneSample();

      // Avoid a runaway catch-up loop if I2C/interrupts cause a large delay.
      if ((int32_t)(micros() - next_sample_us) > (int32_t)(5 * SAMPLE_PERIOD_US)) {
        missed_samples++;
        next_sample_us = micros() + SAMPLE_PERIOD_US;
        break;
      }
    }
  }

  if (dumping) {
    if (!waiting_for_ack) {
      sendCurrentChunk();
    } else if (millis() - last_chunk_send_ms > ACK_TIMEOUT_MS) {
      chunk_retry_count++;
      if (chunk_retry_count > MAX_CHUNK_RETRIES) {
        sendLine("ERR,ACK_TIMEOUT_ABORT,chunk=" + String(current_chunk_start));
        flushBle();
        dumping = false;
        waiting_for_ack = false;
      } else {
        sendLine("RETRY,chunk=" + String(current_chunk_start) + ",attempt=" + String(chunk_retry_count));
        flushBle();
        waiting_for_ack = false;
        sendCurrentChunk();
      }
    }
  }
}

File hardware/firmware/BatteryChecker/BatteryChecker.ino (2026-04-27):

#include <Arduino.h>
#include <Adafruit_TinyUSB.h>
#include <bluefruit.h>

BLEUart bleuart;

static const uint8_t PIN_ADC_BAT_CTRL = 14;
static const uint8_t PIN_BAT_ADC      = 32;
static const uint8_t PIN_CHARGE_STAT  = 23;
static const uint8_t PIN_CHG_CURRENT  = 22;

static const bool USE_50MA_CHARGE = false;

static const float ADC_REF_V = 3.6f;
static const float ADC_MAX = 4095.0f;
static const float BAT_DIVIDER_FACTOR = 2.961f;

int trackedPct = -1;
bool lastCharging = false;
bool firstBatteryPrint = true;

void printBoth(const String& s) {
  Serial.println(s);
  if (Bluefruit.connected()) {
    bleuart.println(s);
  }
}

void startAdv() {
  Bluefruit.Advertising.stop();
  Bluefruit.Advertising.addFlags(BLE_GAP_ADV_FLAGS_LE_ONLY_GENERAL_DISC_MODE);
  Bluefruit.Advertising.addTxPower();
  Bluefruit.Advertising.addService(bleuart);
  Bluefruit.ScanResponse.addName();
  Bluefruit.Advertising.restartOnDisconnect(true);
  Bluefruit.Advertising.setInterval(32, 244);
  Bluefruit.Advertising.setFastTimeout(30);
  Bluefruit.Advertising.start(0);
}

void setChargeCurrent() {
  if (USE_50MA_CHARGE) {
    pinMode(PIN_CHG_CURRENT, INPUT);
  } else {
    pinMode(PIN_CHG_CURRENT, OUTPUT);
    digitalWrite(PIN_CHG_CURRENT, LOW);
  }
}

bool isCharging() {
  pinMode(PIN_CHARGE_STAT, INPUT);
  return digitalRead(PIN_CHARGE_STAT) == LOW;
}

float readBatteryVoltage() {
  pinMode(PIN_ADC_BAT_CTRL, OUTPUT);
  digitalWrite(PIN_ADC_BAT_CTRL, LOW);
  delay(5);

  analogRead(PIN_BAT_ADC);
  delay(2);

  const int N = 8;
  uint32_t sum = 0;

  for (int i = 0; i < N; i++) {
    sum += analogRead(PIN_BAT_ADC);
    delay(2);
  }

  float raw = sum / (float)N;
  return BAT_DIVIDER_FACTOR * ADC_REF_V * raw / ADC_MAX;
}

int batteryPercent(float vbat) {
  if (vbat >= 4.20f) return 100;
  if (vbat <= 3.20f) return 0;

  int pct;

  if (vbat >= 4.00f) {
    pct = 80 + (int)((vbat - 4.00f) / 0.20f * 20.0f);
  } else if (vbat >= 3.85f) {
    pct = 55 + (int)((vbat - 3.85f) / 0.15f * 25.0f);
  } else if (vbat >= 3.70f) {
    pct = 25 + (int)((vbat - 3.70f) / 0.15f * 30.0f);
  } else if (vbat >= 3.50f) {
    pct = 8 + (int)((vbat - 3.50f) / 0.20f * 17.0f);
  } else {
    pct = (int)((vbat - 3.20f) / 0.30f * 8.0f);
  }

  return constrain(pct, 0, 100);
}

String batteryStatusText(bool charging, float vbat) {
  if (charging) return "C";
  if (vbat >= 4.20f) return "NC / Full";
  return "NC";
}

void setup() {
  Serial.begin(115200);
  delay(1200);

  analogReference(AR_DEFAULT);
  analogReadResolution(12);

  setChargeCurrent();

  Bluefruit.begin();
  Bluefruit.setTxPower(4);
  Bluefruit.setName("XIAO_BATTERY");

  bleuart.begin();
  startAdv();

  printBoth("XIAO Battery Monitor Ready");
}

void loop() {
  bool charging = isCharging();
  float vbat = readBatteryVoltage();
  int pct = batteryPercent(vbat);

  bool chargingChanged = !firstBatteryPrint && (charging != lastCharging);
  bool shouldPrint = false;

  if (firstBatteryPrint || chargingChanged) {
    trackedPct = pct;
    shouldPrint = true;
  } 
  else if (charging && pct > trackedPct) {
    trackedPct = pct;
    shouldPrint = true;
  } 
  else if (!charging && pct < trackedPct) {
    trackedPct = pct;
    shouldPrint = true;
  }

  if (shouldPrint) {
    printBoth(
      "S: " + batteryStatusText(charging, vbat) +
      " | B: " + String(vbat, 2) + "V, " +
      String(trackedPct) + "%"
    );
  }

  lastCharging = charging;
  firstBatteryPrint = false;

  while (bleuart.available()) {
    char c = bleuart.read();

    if (c == 'b' || c == 'B') {
      printBoth(
        "S: " + batteryStatusText(charging, vbat) +
        " | B: " + String(vbat, 2) + "V, " +
        String(pct) + "%"
      );
    }
  }

  delay(2000);
}

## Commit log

2026-01-22 Add first single-trial IMU vs MoCap MTC result plot
2026-01-25 Add upper-bound pipeline using MoCap gait events
    Stance/swing windows taken from MoCap IC/TC to establish the best-case
    MTC accuracy before switching to IMU-only event detection.
2026-01-29 Add IMU-only MTC pipeline v1 and summary metrics script
2026-01-30 Add first all-participant IMU-only results (29 Jan run)
    [imu_only_all_summary.csv, per_participant_metrics.csv]
2026-02-01 Add Stage A EventNet stance detector training and trained weights
    Compact 1D dilated CNN (k=7, dilations 1/2/4) on 8 IMU channels with
    participant-held-out validation.
2026-02-03 Add toe-offset calibration results and updated summary (3 Feb run)
    [imu_only_all_summary.csv, toe_offset_calibration.csv]
2026-02-10 Run IMU-only evaluation across all 14 SPC2019 participants
    [imu_only_all_summary.csv]
2026-02-11 Add per-trial summaries and stride-level error exports
    [one_4d91_alltests_summary.csv, one_6dbe_2_alltests_summary.csv, stride_errors.csv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]
2026-02-12 Add frozen-parameter evaluation script and x/z toe-offset calibration
    [toe_offset_calibration_xz.csv]
2026-02-15 Add normal_20 stride errors for 4d91
    [stride_errors_4d91_normal_20_left.csv]
2026-02-16 Add held-out evaluations for 5047, 9b4b and e54d
    [imu_eval_9b4b_alltests.csv, imu_eval_e54d_alltests.csv, stride_errors_5047_fast_10_left.csv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]
2026-02-17 Pipeline v3: cadence-adaptive filtering, two-stage toe calibration, calibration script
    Butterworth cut-offs scaled from gyro-norm step frequency
    (acc = clip(8 f_step, 10, 35) Hz, gyr = clip(6 f_step, 8, 30) Hz).
2026-02-18 Refactor: split pipeline into core module + calibrate/evaluate stages
    pipeline_core.py orchestrates the phase functions so Phase 1.1-1.6 is
    computed once and only Phase 1.8-1.9 is re-run during calibration.
2026-02-19 Calibration: multi-test RMSE/bias reporting over x/y grid
    [imu_eval_4d91_alltests_tc2tc.csv]
2026-02-20 Evaluation cleanup and long-trial stride errors
    [stride_errors_4d91_long_left.csv, toe_offset_4d91_left.csv]
2026-03-02 Latest pipeline revision with updated 4d91 results
    [imu_eval_4d91_alltests.csv, stride_errors_4d91_slow_10_left.csv, stride_errors_4d91_slow_20_left.csv]
2026-04-14 Hardware: LED test sketch
2026-04-17 Enclosure CAD V1: initial top/bottom casing parts
    [Bottom_Part.SLDPRT, Top_Part.SLDPRT]
2026-04-22 Enclosure CAD V2: shell, sliding door, switch fit part and full casing assembly
    [Bottom_Part_V2.SLDPRT, Bottom_Part_V2.STL, Casing.SLDASM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]
2026-04-23 Enclosure CAD V3: revised parts with STL exports for printing
    [Bottom_Part_V3.SLDPRT, Bottom_Part_V3.STL, Shell_Part_V3t.SLDPRT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]
2026-04-23 Enclosure CAD V4: revised top, bottom, shell and sliding door
    [Bottom_Part_V4.SLDPRT, Bottom_Part_V4.STL, Shell_Part_V4.SLDPRT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]
2026-04-24 Enclosure CAD V5: revised parts
    [Bottom_Part_V5.SLDPRT, Bottom_Part_V5.STL, Shell_Part_V5.SLDPRT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]
2026-04-24 Enclosure CAD V6: revised bottom part
    [Bottom_Part_V6.SLDPRT, Bottom_Part_V6.STL, Shell_Part_V6.SLDPRT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]
2026-04-27 Hardware: battery voltage checker sketch
2026-04-27 Enclosure CAD V7: final shell revision
    [Bottom_Part_V7.SLDPRT, Shell_Part_V7.SLDPRT, Shell_Part_V7.STL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]
2026-05-01 Add first BMI160 test recordings
    [imu_TEMP_20260501_232221.csv, imu_TEMP_20260502_000206.csv]
2026-05-02 Hardware: RAM-buffered 100 Hz recording with ACK/NACK chunked BLE CSV transfer
    [imu_20260502_115605.csv, imu_20260502_121123.csv, imu_20260502_121859.csv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]
2026-05-02 IMU calibration stages 0-2: axis detection, accel calibration, shoe gyro calibration
    [Back_x_minus.csv, Bottom_z_minus.csv, Front_x_plus.csv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]
2026-05-02 Host logger: apply stage 0-2 calibration and save RAW + CALIBRATED CSVs
    [imu_20260502_191304_CALIBRATED.csv, imu_20260502_191304_RAW.csv]
2026-05-02 Firmware V2: 200 Hz sampling, +/-16 g and +/-2000 dps ranges for walking
2026-05-02 Save session calibration outputs and calibrated walking recording
    [Back_x_minus_20260502_222358.csv, Bottom_z_minus_20260502_222603.csv, Front_x_plus_20260502_222256.csv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]
2026-05-02 Waveform comparison v1 outputs (raw sensor frame)
    [comparison_summary.csv, dataset_4d91_normal10_r_instep_window.csv, my_bmi160_right_instep_window.csv]
2026-05-02 Waveform comparison v2: gaitmap frame convention, deg/s gyro, window selection
    [comparison_summary.csv, dataset_4d91_normal10_r_instep_window_gaitmap_frame.csv, my_bmi160_right_instep_window_transformed_gaitmap_frame.csv]
2026-10-09 Add design diagrams, pin requirements, expand README
    - docs/figures: system overview, EventNet, MTC and BMI160 pipeline
    figures, SPC2019 walking trials and the BMI160/XIAO schematic
    - docs/diagrams_source: editable draw.io sources
    - requirements.txt pinned to the original Python 3.10 environment
    - README: embedded figures and a Hardware section
